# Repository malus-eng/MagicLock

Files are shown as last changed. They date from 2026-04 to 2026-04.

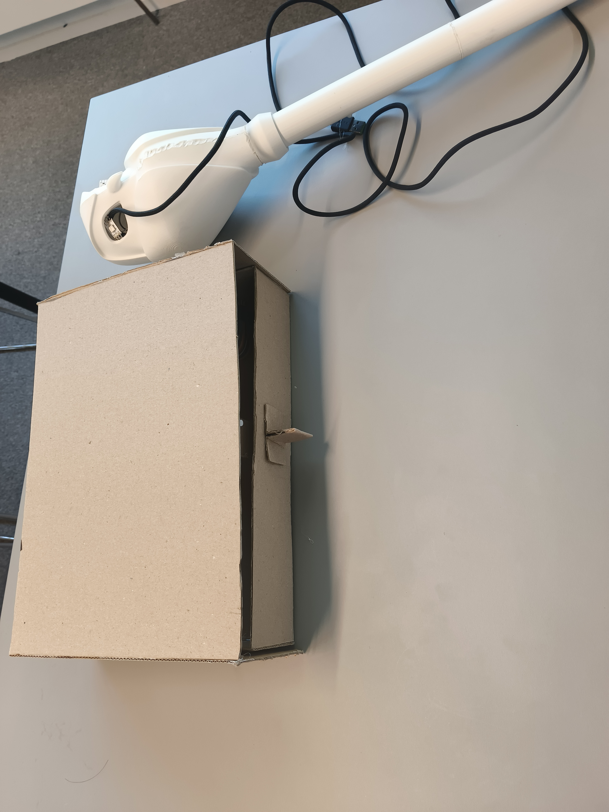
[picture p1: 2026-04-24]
docs/PoC V1.0/PoC V1.0_3.png

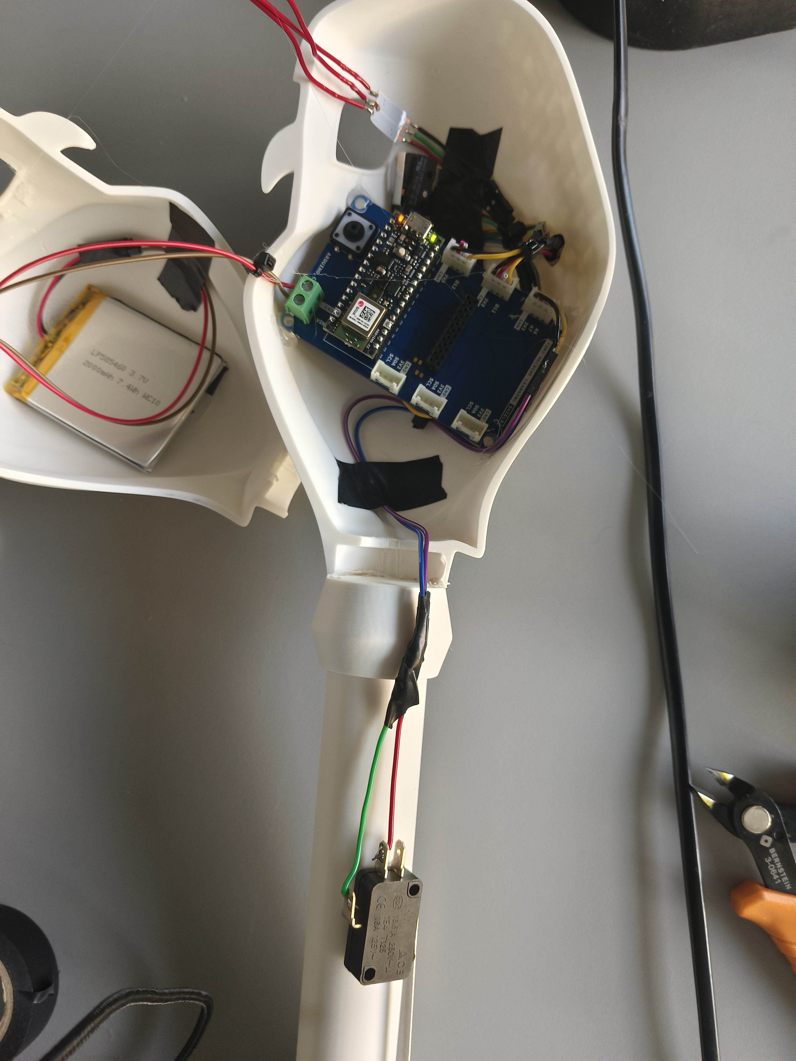
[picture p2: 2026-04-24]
docs/PoC V1.0/PoC V1.0_1.jpg

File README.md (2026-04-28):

## Project Overview
This project, developed a decentralized authentication system using Edge AI and Bluetooth Low Energy (BLE). It features a "Magic Wand" (Arduino Nano 33 BLE) that recognizes spatial gestures (digits '1' and '0') using an onboard IMU and a neural network model. Upon successful authentication of a 4-digit sequence, the wand triggers a "Smart Locker" (ESP32-S3) to actuate a physical lock via an SG90 servo.

## System Architecture
The system follows a local Machine-to-Machine (M2M) communication pattern:
- **Client (Magic Wand)**: Performs real-time IMU sampling (100Hz), TinyML inference, and state management.
- **Server (Smart Locker)**: Acts as a BLE peripheral, validating received credentials and driving high-current actuators (Servo).

## Hardware Components
- **Microcontrollers**: Arduino Nano 33 BLE, ESP32-S3 (DevKitM).
- **Sensors/Actuators**: LSM9DS1 IMU (onboard), SG90 Servo Motor, WS2812B NeoPixel LEDs.
- **Interfaces**: Limit switches (D12 for Power, A6 for Recording).

## Repository Structure
- `/src/wand_nano33ble`: Arduino source code for the gesture transmitter.
- `/src/locker_esp32s3`: PlatformIO project for the receiver and actuator.
- `/data`: Raw CSV datasets and automated collection scripts (`record.py`).
- `/hardware`: Wiring diagrams and BOM.

## Key Technical Solutions
- **I2C Bus Stability**: Implemented hardware power cycling (`IMU.end()`) during inference to prevent I2C FIFO overflow and Mbed OS kernel panics.
- **Memory Optimization**: Replaced `String` classes with static `char[]` arrays to eliminate heap fragmentation in memory-constrained environments.
- **Flash Partitioning**: Configured `board = esp32-s3-devkitm-1` in PlatformIO to resolve binary image header size mismatches.

## Installation & Deployment
1. **Model**: Import the Edge Impulse `.zip` library from `/src` into your Arduino IDE.
2. **Locker**: Deploy the PlatformIO project in `/src/locker_esp32s3` to the ESP32-S3.
3. **Wand**: Upload the `.ino` sketch to the Nano 33 BLE, ensuring the Edge Impulse header name matches your build.

# Define the content for the Project Report

## 1. Problem Context and Research Question
In the context of touchless interaction and physical security, traditional biometric or mechanical locks often lack flexibility or require centralized network infrastructure. This project investigates the feasibility of deploying a localized, low-latency gesture recognition system using TinyML. The primary research question is: *How can high-frequency spatial temporal data be classified on ultra-low-power microcontrollers to provide robust, decentralized access control?*

## 2. Data Collection and Processing
The dataset was built using a custom Python automation script (`record.py`) interfacing with the LSM9DS1 IMU. 
- **Sampling Strategy**: 3-axis accelerometer data was sampled at 100Hz.
- **Classes**: Three labels were defined: '1', '0', and 'idle'. The 'idle' class is critical for real-world deployment to minimize false positives caused by accidental movement.
- **Preprocessing**: Data was processed using Spectral Analysis in Edge Impulse to extract frequency-domain features, effectively reducing the noise inherent in manual gesture execution.

## 3. Documentation of Methods and Results
### 3.1 Model Architecture
A Convolutional Neural Network (CNN) architecture was selected for its strength in recognizing patterns in time-series data. The model was quantized to int8 to fit the 256KB RAM constraints of the Nano 33 BLE while maintaining >95% accuracy in controlled testing.

### 3.2 Technical Implementation Challenges
The development process involved several critical iterations:
- **Watchdog & RTOS Conflicts**: Early versions suffered from system crashes during the 1-second inference window. By implementing a 1ms `delay()` in the sampling loop and temporarily suspending the IMU bus (`IMU.end()`), the Mbed OS watchdog was satisfied, ensuring system stability.
- **Flash Memory Misalignment**: The ESP32-S3 initially reported binary header size errors (8192k vs 4096k). This was solved by reconfiguring the PlatformIO environment to target the `devkitm-1` variant, correctly aligning the partition table with the physical hardware.

## 4. Results and Testing
Functional testing confirmed a seamless "Sleep-Wake-Identify-Transmit" loop. The wand successfully transmits the "1010" credential over BLE to the locker, which rotates the servo to 90 degrees with a green LED visual confirmation. False rejection rates were lowered by implementing a 0.6 confidence threshold for each digit recognition.

## 5. Critical Reflection
### 5.1 Limitations
- **User Specificity**: The model currently exhibits overfitting to the primary developer's gesture speed. Expanding the dataset to include diverse biometric profiles would improve generalizability.
- **BLE Security**: The current protocol uses plaintext transmission. Future iterations should implement a challenge-response handshake with cryptographic nonces to prevent replay attacks.

### 5.2 Future Improvements
Transitioning from a basic CNN to a Gated Recurrent Unit (GRU) might better handle the variable-length nature of human gestures. Additionally, utilizing the ESP32-S3's hardware acceleration for BLE encryption would significantly enhance the system's security posture.

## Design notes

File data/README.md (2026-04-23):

# Dataset and Data Collection Scripts

This folder contains the raw dataset used to train the gesture recognition model in Edge Impulse, along with the custom Python script (`record.py`) developed for efficient data acquisition.

## Dataset Overview
The dataset consists of time-series accelerometer data (X, Y, Z axes) captured at approximately 100Hz using the onboard LSM9DS1 IMU of the Arduino Nano 33 BLE.
The data is categorized into three classes to ensure robust recognition and minimize false positives:
* `one`: Data capturing the motion of drawing the number '1' in the air.
* `zero`: Data capturing the motion of drawing the number '0' in the air.
* `idle`: Background noise and random movements to serve as a negative class, preventing the model from misclassifying casual movements.

All raw data files are saved in standard CSV format, making them directly compatible with the Edge Impulse ingestion pipeline.

## Data Collection Tool (`record.py`)
To streamline the data collection process and ensure consistency across samples, a custom Python script using the `pyserial` library was developed. 

**How it works:**
1.  **Serial Communication**: The script establishes a serial connection with the Arduino Nano 33 BLE (baud rate: 115200).
2.  **Trigger Mechanism**: Upon pressing 'Enter' on the PC, the script sends a trigger command (`'r'`) to the wand.
3.  **Automated Logging**: The wand begins recording IMU data. The Python script listens to the serial port, extracts the payload (ignoring headers/footers), and automatically saves the continuous data stream into sequentially numbered CSV files (e.g., `one_01.csv`, `one_02.csv`).
4.  **Validation**: It includes a safety check to discard incomplete recordings (e.g., files with fewer than 50 lines of data).

**Usage:**
```bash
# Ensure the Arduino IDE Serial Monitor is closed before running
python record.py

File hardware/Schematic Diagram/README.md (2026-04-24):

### 2. Hardware List & Wiring Summary

#### Device 1: Magic Wand (Client / Transmitter)
**Core Board**: Arduino Nano 33 BLE (Built-in LSM9DS1 9-axis IMU)

* **Wake/Power Button**:
    * Pin 1: Connects to the **`D12`** pin on the Nano 33 BLE.
    * Pin 2: Connects to **`GND`**.
* **Record Button**:
    * Pin 1: Connects to the **`A6`** pin on the Nano 33 BLE.
    * Pin 2: Connects to **`GND`**.
* **Status Indicator (WS2812B NeoPixel Module - 2 LEDs)**:
    * `DIN` (Data In): Connects to the **`D11`** pin on the Nano 33 BLE.
    * `VCC` (Power): Connects to the **`3.3V`** pin on the Nano 33 BLE.
    * `GND` (Ground): Connects to **`GND`**.

#### Device 2: Lock Box (Server / Receiver)
**Core Board**: ESP32-S3 (DevKitC / DevKitM)

* **Physical Lock Actuator (SG90 Servo)**:
    * `Signal` (Orange/Yellow wire): Connects to the **`GPIO 4`** pin on the ESP32-S3.
    * `VCC` (Red power wire): Connects to the **`5V`** pin (or VBUS). 
    * `GND` (Brown/Black wire): Connects to **`GND`**.
* **Status Indicator (WS2812B NeoPixel Module - 1 LED)**:
    * `DIN` (Data In): Connects to the **`GPIO 5`** pin on the ESP32-S3.
    * `VCC` (Power): Connects to **`3.3V`** or **`5V`** (WS2812B is usually compatible with both; connecting to 3.3V is recommended to prevent logic level mismatch).
    * `GND` (Ground): Connects to **`GND`**.

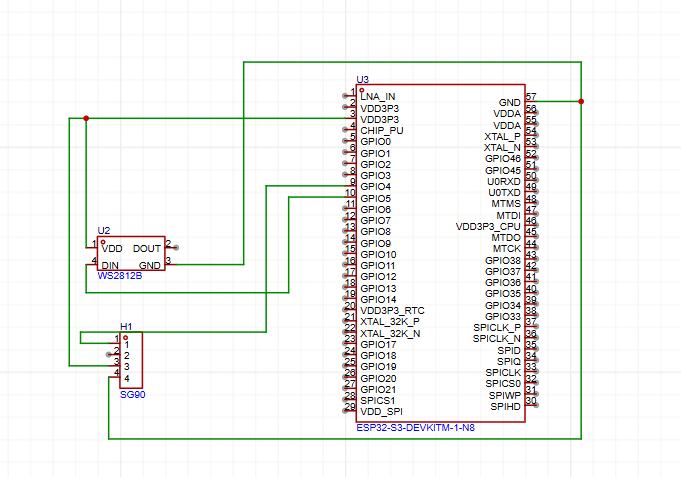
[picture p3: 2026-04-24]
hardware/Schematic Diagram/locker_schematic.png

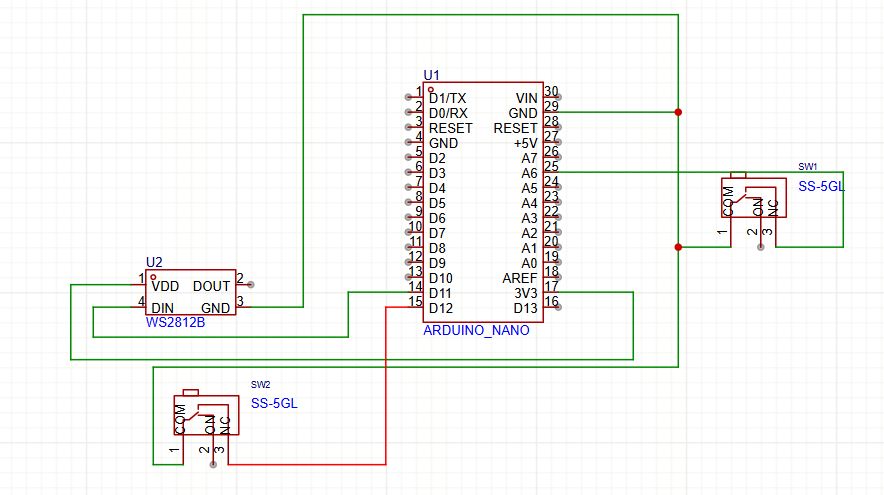
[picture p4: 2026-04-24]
hardware/Schematic Diagram/staff_schematic.png

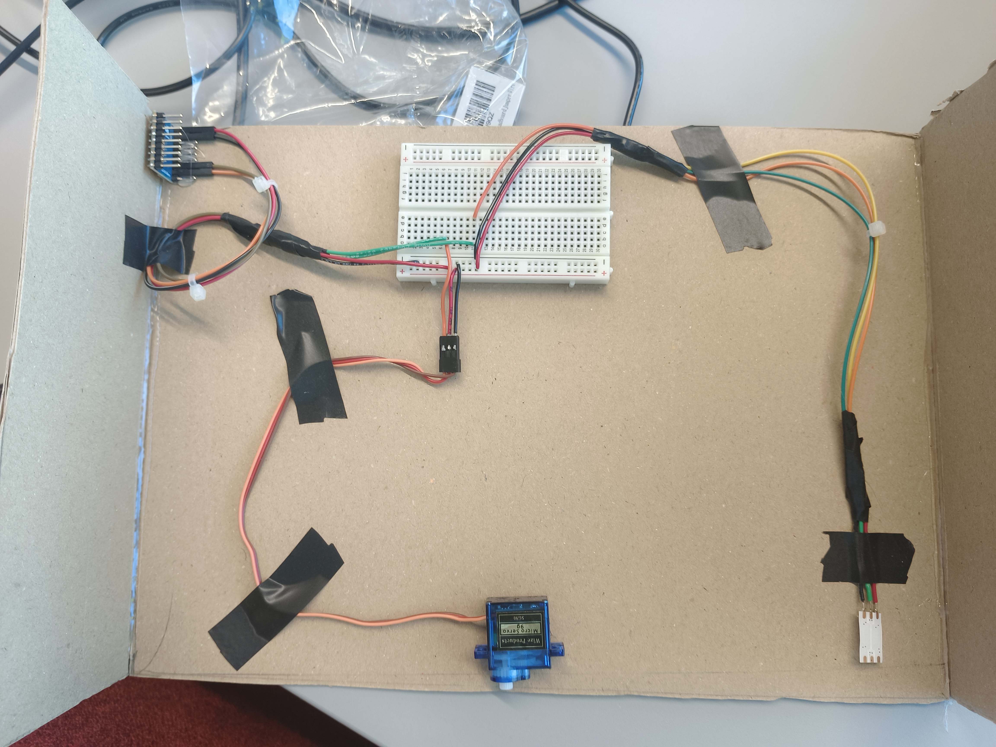
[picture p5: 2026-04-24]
docs/PoC V1.0/PoC V1.0_2.png

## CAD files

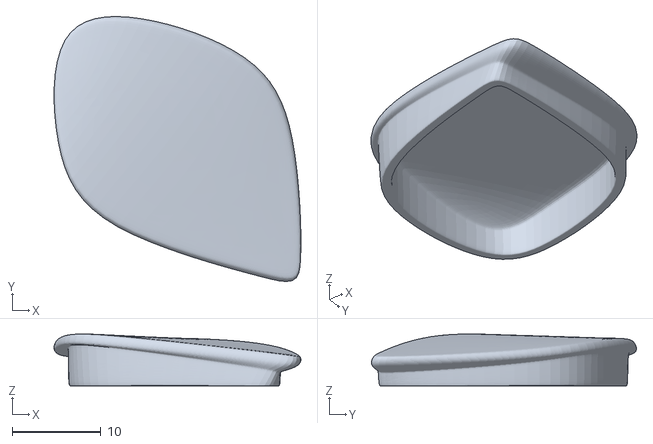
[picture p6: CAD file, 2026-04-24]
hardware/3D_Printing_Shell/STL-Owl_House_Owlbert_Eye_1-3Demon.stl
27.9 x 29.9 x 5.86

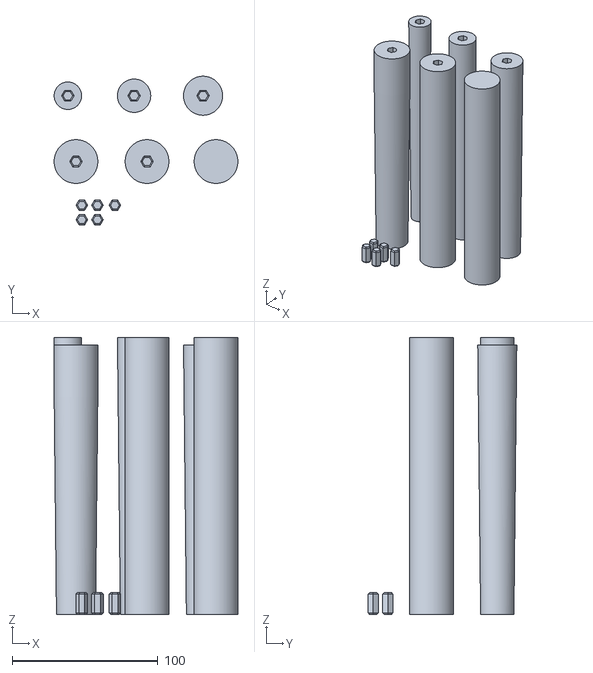
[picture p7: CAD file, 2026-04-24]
hardware/3D_Printing_Shell/STL-Staff_Pins_113cm-3Demon.stl
126.0 x 102.0 x 190.0

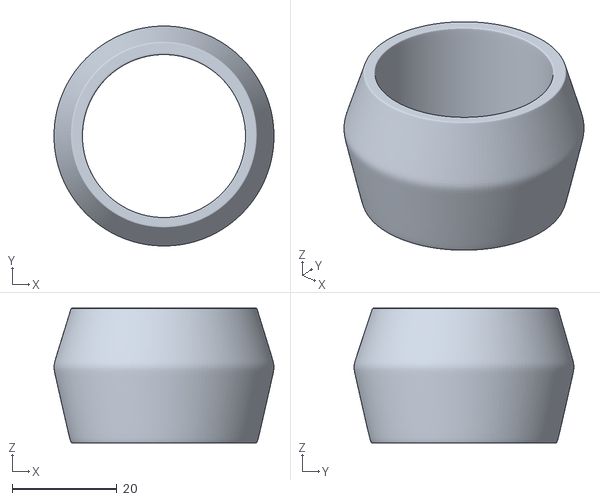
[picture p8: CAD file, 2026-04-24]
hardware/3D_Printing_Shell/STL-Owl_House_Owlbert_Stand-3Demon.stl
42.1 x 42.0 x 25.8

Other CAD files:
hardware/3D_Printing_Shell/STL-Owl_House_Owlbert_Eye_2-3Demon.stl

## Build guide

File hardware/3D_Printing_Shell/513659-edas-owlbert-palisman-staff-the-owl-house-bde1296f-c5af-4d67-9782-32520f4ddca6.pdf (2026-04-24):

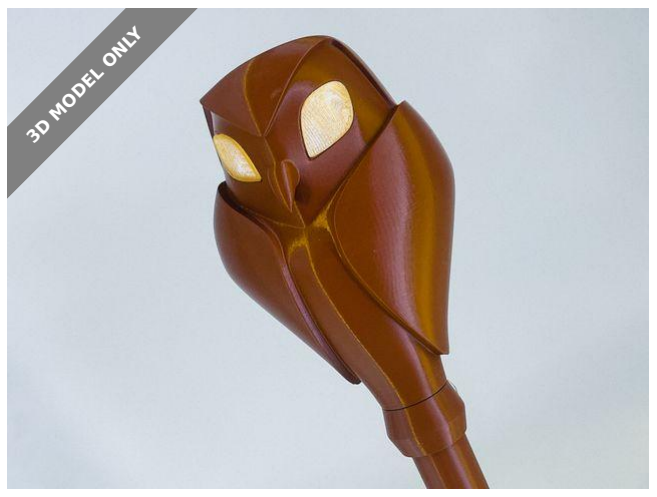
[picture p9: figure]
3D MODEL ONLY

# Summary

3D printable model of Eda's Owlbert Palisman Staff from the animated

series The Owl House. You can add LED lights inside

Costumes & Accessories (https://printables.com/model?categoryId=76) | > | Props (https://printables.com/model?categoryId=81)
Tags: owl | owlbert | staff | owlhouse | palisman

### This is a digital 3D printable model of Eda's Owlbert Palisman Staff

from the animated series The Owl House.

The download contains pieces of the model ready to be 3D printed on a

200 mm print bed (STL) All cut parts are placed on the print bed as we

would print them to save you time. The Owl staff is hollow and allows

printing the eyes separately (I printed the with yellow-seethrough

filament). You can add LED lights inside.

Check out the whole Palismen collection! (https://3d-mon.com/3d-model/groupe/unisex3dprintmodel/the-owl-house-palismen-collection/)

The files contain 2 versions of the staff. 70cm and 113cm long and are

split among smaller printable parts which can be connected by

hexagonal pegs.

### SIZE

At 100% scale the Owl’s dimensions are approximately:

3Demon (https://printables.com/@3Demon)

# Eda's Owlbert Palisman Staff -The Owl House

VIEW IN BROWSER (https://printables.com/model/513659-edas-owlbert-palisman-staff-the-owl-house)

updated 26. 6. 2023 | published 26. 6. 2023

# Model files

### Width 124 mm Length 109 mm Height 207 mm

You can scale the model as you wish but we can’t guarantee that at a

much smaller size the model will print well. We create our 3D models on

### our average-sized body template. Read about the sizing and how to

scale the models to fit your body here. (https://3d-mon.com/sizing-a-3d-printable-model-for-cosplay/)

### 3D PRINTING SETTINGS

We use these settings for most of our prints:

Layer height 0.15 mm

Infill 15%

Supports 45°
We use a 10 mm brim for tall parts with a small base for better bed

adhesion.

Printing settings will vary greatly depending on your specific printer.

We try to make the models in a way that uses as little support material as

possible.

This model is meant to be post-processed after printing. This can be

gluing, sanding, painting, etc. We use hex-pegs (included in the files) that

will help you connect the cut pieces of the model.

Do you like the model and don't have a 3D printer? There are lots of

people who offer 3D printing services these days. Try searching for

someone who offers them in your area.

This fan-made model was brought to life by 3Demon. We are a group of

modeling and 3d printing enthusiasts based in Prague, Czech Republic.

We’ve been making 3D printable models for more than a decade. We make

a lot of cosplay accessories but we also make all sorts of interesting 3D

models. You can join our community or just look at more of our creations

### here. (https://3d-mon.com/links/)

stl-owl_house_owlbert_stand-3demon.stl

stl-owl_house_owlbert_eye_2-3demon.stl

# License

This work is licensed under a

Creative Commons (4.0 International License)

Attribution-NonCommercial (http://creativecommons.org/licenses/by-nc/4.0/)

✖ | Sharing without ATTRIBUTION
✔ | Remix Culture allowed
✖ | Commercial Use
✖ | Free Cultural Works
✖ | Meets Open Definition

stl-owl_house_owlbert_eye_1-3demon.stl

stl-owl_house_owlbert-3demon.stl

stl-staff_pins_70cm-3demon.stl

stl-staff_pins_113cm-3demon.stl

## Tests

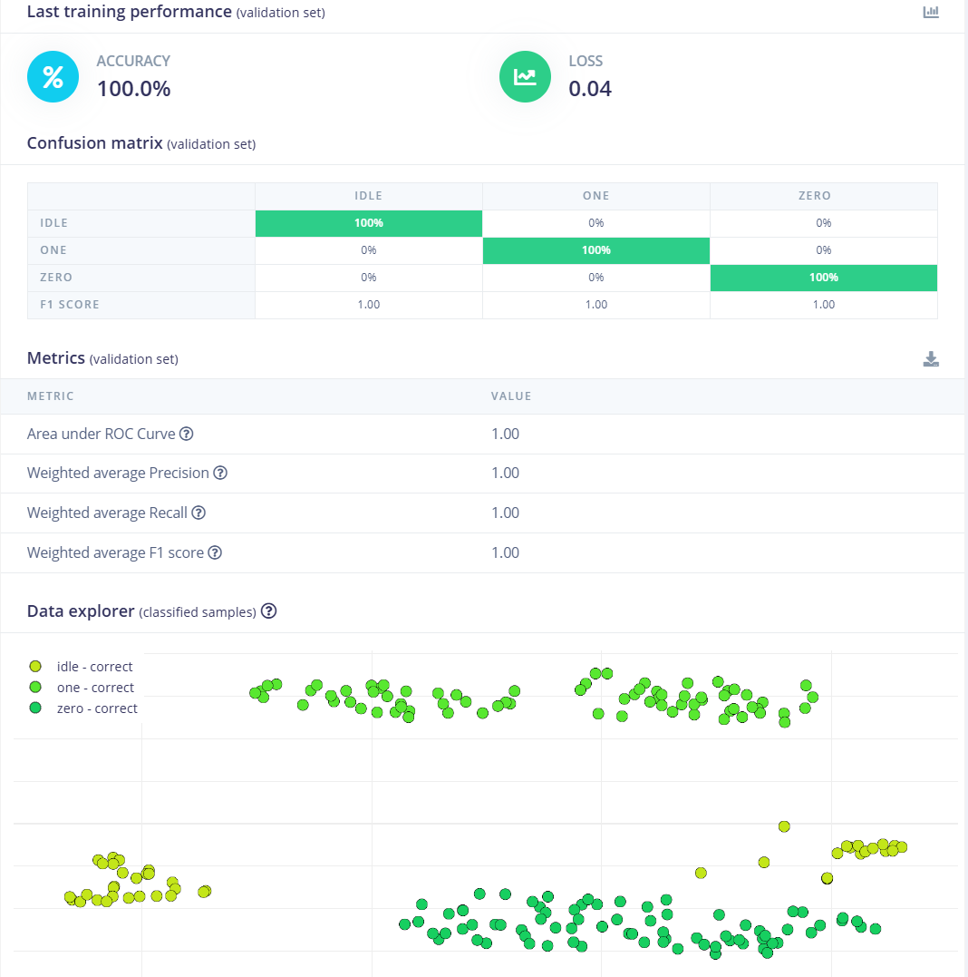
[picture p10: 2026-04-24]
docs/model_performance/Confusion matrix (validation set).png

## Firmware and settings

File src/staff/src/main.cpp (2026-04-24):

#include <Arduino.h>
#include <tiandiguailikaipizhixing-project-1_inferencing.h> 
#include <ArduinoBLE.h>
#include <Arduino_LSM9DS1.h>
#include <Adafruit_NeoPixel.h>

// ================= Pins & Hardware Config =================
#define LED_PIN           11
#define WAKE_BUTTON_PIN   12
#define RECORD_BUTTON_PIN A6
#define NUM_LEDS          2
void sendPasswordToLocker(const char* pwd);
// ================= Smart Power Management =================
// 5 minutes = 5 * 60 * 1000 = 300,000 milliseconds
unsigned long IDLE_TIMEOUT = 300000; 
unsigned long lastActivityTime = 0;

Adafruit_NeoPixel pixels(NUM_LEDS, LED_PIN, NEO_GRB + NEO_KHZ800);

const char* lockerServiceUUID = "19b10000-e8f2-537e-4f6c-d104768a1214";
const char* lockerCharUUID    = "19b10001-e8f2-537e-4f6c-d104768a1214";

char currentPassword[5] = {0}; 
int pwdIndex = 0;              

enum WandState { SLEEP_MODE, WAKE_MODE };
WandState currentState = SLEEP_MODE;

float features[EI_CLASSIFIER_DSP_INPUT_FRAME_SIZE];

int raw_feature_get_data(size_t offset, size_t length, float *out_ptr) {
    memcpy(out_ptr, features + offset, length * sizeof(float));
    return 0;
}

// Helper function: Handle sleep mode transition uniformly
void goToSleep() {
  Serial.println("Wand entering sleep mode...");
  pixels.clear(); 
  pixels.show();
  currentState = SLEEP_MODE;
  memset(currentPassword, 0, sizeof(currentPassword));
  pwdIndex = 0;
}

void setup() {
  Serial.begin(115200);
  pinMode(WAKE_BUTTON_PIN, INPUT_PULLUP);
  pinMode(RECORD_BUTTON_PIN, INPUT_PULLUP);
  
  pixels.begin();
  pixels.setBrightness(30); 
  pixels.clear(); pixels.show();

  if (!IMU.begin()) { Serial.println("IMU Error"); while (1); }
  if (!BLE.begin()) { Serial.println("BLE Error"); while (1); }
  
  Serial.println("🪄 Wand initialization complete.");
}

void loop() {
  // ---------------- [State 1: Sleep Mode] ----------------
  if (currentState == SLEEP_MODE) {
    if (digitalRead(WAKE_BUTTON_PIN) == LOW) {
      delay(50);
      if (digitalRead(WAKE_BUTTON_PIN) == LOW) {
        Serial.println("Woken up! Entering active state...");
        pixels.fill(pixels.Color(255, 255, 255)); pixels.show();
        currentState = WAKE_MODE;
        lastActivityTime = millis(); // Record activation starting point
        while(digitalRead(WAKE_BUTTON_PIN) == LOW); 
      }
    }
  }

  // ---------------- [State 2: Active Mode] ----------------
  else if (currentState == WAKE_MODE) {
    
    // Check for auto-shutdown timeout
    if (millis() - lastActivityTime > IDLE_TIMEOUT) {
      Serial.println("5-minute timeout, auto-power off.");
      goToSleep();
      return; 
    }

    // Check for manual shutdown via D12
    if (digitalRead(WAKE_BUTTON_PIN) == LOW) {
      delay(50);
      if (digitalRead(WAKE_BUTTON_PIN) == LOW) {
        Serial.println("User manually pressed the power button.");
        goToSleep();
        while(digitalRead(WAKE_BUTTON_PIN) == LOW); 
        return;
      }
    }

    // --- Recognition Logic (Press A6) ---
    if (digitalRead(RECORD_BUTTON_PIN) == LOW) {
      lastActivityTime = millis(); // Refresh activity timestamp
      Serial.println("Start recording...");
      pixels.fill(pixels.Color(0, 0, 255)); pixels.show();
      
      int feature_ix = 0;
      unsigned long last_sample_time = micros();
      unsigned long sample_interval = 1000000 / EI_CLASSIFIER_FREQUENCY;

      while (digitalRead(RECORD_BUTTON_PIN) == LOW && (feature_ix + 2) < EI_CLASSIFIER_DSP_INPUT_FRAME_SIZE) {
        if (micros() - last_sample_time >= sample_interval) {
          last_sample_time = micros(); 
          float x, y, z;
          if (IMU.accelerationAvailable()) {
            IMU.readAcceleration(x, y, z);
            features[feature_ix++] = x;
            features[feature_ix++] = y;
            features[feature_ix++] = z;
          }
        }
        delay(1); 
      }

      while (feature_ix < EI_CLASSIFIER_DSP_INPUT_FRAME_SIZE) {
         if (feature_ix >= 3) { features[feature_ix] = features[feature_ix - 3]; }
         else { features[feature_ix] = 0; }
         feature_ix++;
      }

      pixels.fill(pixels.Color(255, 255, 255)); pixels.show();
      IMU.end(); 
      delay(100);

      signal_t features_signal;
      features_signal.total_length = sizeof(features) / sizeof(features[0]);
      features_signal.get_data = &raw_feature_get_data;
      ei_impulse_result_t result = { 0 };
      run_classifier(&features_signal, &result, false);

      IMU.begin();
      delay(50);

      String recognizedNumber = "";
      float max_value = 0;
      for (uint16_t i = 0; i < EI_CLASSIFIER_LABEL_COUNT; i++) {
          if (result.classification[i].value > max_value) {
              max_value = result.classification[i].value;
              recognizedNumber = result.classification[i].label;
          }
      }
      
      if (max_value > 0.6) {
         if (recognizedNumber == "one" || recognizedNumber == "1") {
             if (pwdIndex < 4) { currentPassword[pwdIndex++] = '1'; }
         } 
         else if (recognizedNumber == "zero" || recognizedNumber == "0") {
             if (pwdIndex < 4) { currentPassword[pwdIndex++] = '0'; }
         }
         Serial.print("Current password: "); Serial.println(currentPassword);
         lastActivityTime = millis(); // ⚡ Successful recognition counts as activity
      }

      if (pwdIndex >= 4) {
        Serial.println("Password complete, firing!");
        sendPasswordToLocker(currentPassword);
        
        // Reset current password buffer but keep the wand active
        memset(currentPassword, 0, sizeof(currentPassword));
        pwdIndex = 0;
        Serial.println("Reset complete, waiting for next gesture...");
        lastActivityTime = millis(); // ⚡ Firing complete, reset timer
      }
      delay(500); 
    } 
    else {
      float dummyX, dummyY, dummyZ;
      while (IMU.accelerationAvailable()) { IMU.readAcceleration(dummyX, dummyY, dummyZ); }
      delay(10); 
    }
  }
}

void sendPasswordToLocker(const char* pwd) {
  BLEDevice peripheral;
  BLE.scan(); 
  unsigned long startMillis = millis();
  
  Serial.println("Radar fully active, searching for [SmartBenchLock] ...");
  
  while (millis() - startMillis < 5000) {
    peripheral = BLE.available();
    if (peripheral) {
      if (peripheral.localName() == "SmartBenchLock" || peripheral.hasService(lockerServiceUUID)) {
        Serial.println("Target locked! Stopping scan.");
        BLE.stopScan();
        break;
      }
    }
  }

  if (peripheral && (peripheral.localName() == "SmartBenchLock" || peripheral.hasService(lockerServiceUUID))) {
    Serial.println("Attempting physical connection...");
    if (peripheral.connect()) {
      Serial.println("Connection successful! Initiating hack...");
      if (peripheral.discoverAttributes()) {
        BLECharacteristic lockerChar = peripheral.characteristic(lockerCharUUID);
        if (lockerChar) {
          Serial.print("Injecting ultimate password: "); Serial.println(pwd);
          lockerChar.writeValue((const uint8_t*)pwd, strlen(pwd));
          Serial.println("Injection complete!");
        }
      }
      peripheral.disconnect();
    } else {
      Serial.println("Failed to establish connection!");
    }
  } else {
    Serial.println("Scan timeout, locker not found nearby.");
  }
}

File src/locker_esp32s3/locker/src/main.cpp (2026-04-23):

#include <Arduino.h>
#include <BLEDevice.h>
#include <BLEServer.h>
#include <BLEUtils.h>
#include <BLE2902.h>
#include <ESP32Servo.h>
#include <Adafruit_NeoPixel.h>

// ================= Hardware Pins & Parameters =================
#define SERVO_PIN 4       
#define LED_PIN   5       
#define NUM_LEDS  1       
#define CORRECT_PASS "1010" // The Ultimate Password

Servo myServo;
Adafruit_NeoPixel pixels(NUM_LEDS, LED_PIN, NEO_GRB + NEO_KHZ800);

// ================= BLE UUIDs =================
#define SERVICE_UUID        "19b10000-e8f2-537e-4f6c-d104768a1214"
#define CHARACTERISTIC_UUID "19b10001-e8f2-537e-4f6c-d104768a1214"

// ================= Global States =================
int currentAngle = 0;           // 0=Locked, 90=Unlocked
unsigned long errorTimer = 0;   
bool isErrorMode = false;       

class MyServerCallbacks: public BLEServerCallbacks {
    void onConnect(BLEServer* pServer) {
      Serial.println(" Magic Wand Connected!");
    }
    void onDisconnect(BLEServer* pServer) {
      Serial.println(" Connection lost, restarting advertising...");
      BLEDevice::startAdvertising(); 
    }
};

class MyCallbacks: public BLECharacteristicCallbacks {
    void onWrite(BLECharacteristic *pCharacteristic) {
      std::string rxValue = pCharacteristic->getValue();
      
      if (rxValue.length() > 0) {
        String receivedPass = "";
        for (int i = 0; i < rxValue.length(); i++) {
          receivedPass += rxValue[i];
        }
        
        Serial.print("📡 Received code: "); Serial.println(receivedPass);

        if (receivedPass == CORRECT_PASS) {
          isErrorMode = false;
          // State toggle logic: if closed, open it; if open, close it.
          if (currentAngle == 0) {
            Serial.println("[Password Correct] Green light on, unlocking (90°)");
            currentAngle = 90;
          } else {
            Serial.println("[Password Correct] Green light on, locking (0°)");
            currentAngle = 0;
          }
          myServo.write(currentAngle);
          pixels.fill(pixels.Color(0, 255, 0)); // Green light
          pixels.show();
          
          delay(2000);
          pixels.fill(pixels.Color(0, 0, 255)); // Return to standby blue light
          pixels.show();
        } 
        else {
          Serial.println("[Password Incorrect] Red light warning");
          isErrorMode = true;
          errorTimer = millis(); 
          pixels.fill(pixels.Color(255, 0, 0)); 
          pixels.show();
        }
      }
    }
};

void setup() {
  Serial.begin(115200);

  pixels.begin();
  pixels.setBrightness(100);
  pixels.fill(pixels.Color(0, 0, 255)); 
  pixels.show();

  ESP32PWM::allocateTimer(0);
  ESP32PWM::allocateTimer(1);
  ESP32PWM::allocateTimer(2);
  ESP32PWM::allocateTimer(3);
  myServo.setPeriodHertz(50);
  myServo.attach(SERVO_PIN, 500, 2400);
  myServo.write(0); 

  BLEDevice::init("SmartBenchLock"); 
  BLEServer *pServer = BLEDevice::createServer();
  pServer->setCallbacks(new MyServerCallbacks());

  BLEService *pService = pServer->createService(SERVICE_UUID);
  BLECharacteristic *pCharacteristic = pService->createCharacteristic(
                                         CHARACTERISTIC_UUID,
                                         BLECharacteristic::PROPERTY_READ |
                                         BLECharacteristic::PROPERTY_WRITE
                                       );

  pCharacteristic->setCallbacks(new MyCallbacks());
  pCharacteristic->setValue("Init");
  pService->start();

  BLEAdvertising *pAdvertising = BLEDevice::getAdvertising();
  pAdvertising->addServiceUUID(SERVICE_UUID);
  pAdvertising->setScanResponse(true);
  BLEDevice::startAdvertising();

  Serial.println("=== Smart Locker Ready (Standby Blue Light) ===");
}

void loop() {
  if (isErrorMode && (millis() - errorTimer > 2500)) {
    isErrorMode = false;
    Serial.println("Warning ended, returning to standby blue light");
    pixels.fill(pixels.Color(0, 0, 255)); 
    pixels.show();
  }
  delay(20); 
}

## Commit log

2026-04-24 Add README with hardware list and wiring summary
    Added a detailed hardware list and wiring summary for the Magic Wand and Lock Box devices.
2026-04-28 Update README by removing license and print statement
    Removed license section and a print statement from the README.
